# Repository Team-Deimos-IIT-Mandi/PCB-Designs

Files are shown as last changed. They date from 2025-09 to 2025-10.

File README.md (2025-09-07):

# PCB-Designs Repository

**Team Deimos - IIT Mandi**





This repository contains PCB designs for various robotic systems including drive systems, power distribution, robotic arm control, and miscellaneous components developed by Team Deimos.

## 🖼️ Featured Designs

<table>
<tr>
<td width="50%">

### Power Distribution Network
Power Distribution PCB
*24V to 5V Buck Converter with Protection*

</td>
<td width="50%">

### Motor Control PCB
Motor Control PCB
*Rover Motor Control with ESP32 & CAN*

### Integrated Drive PCB
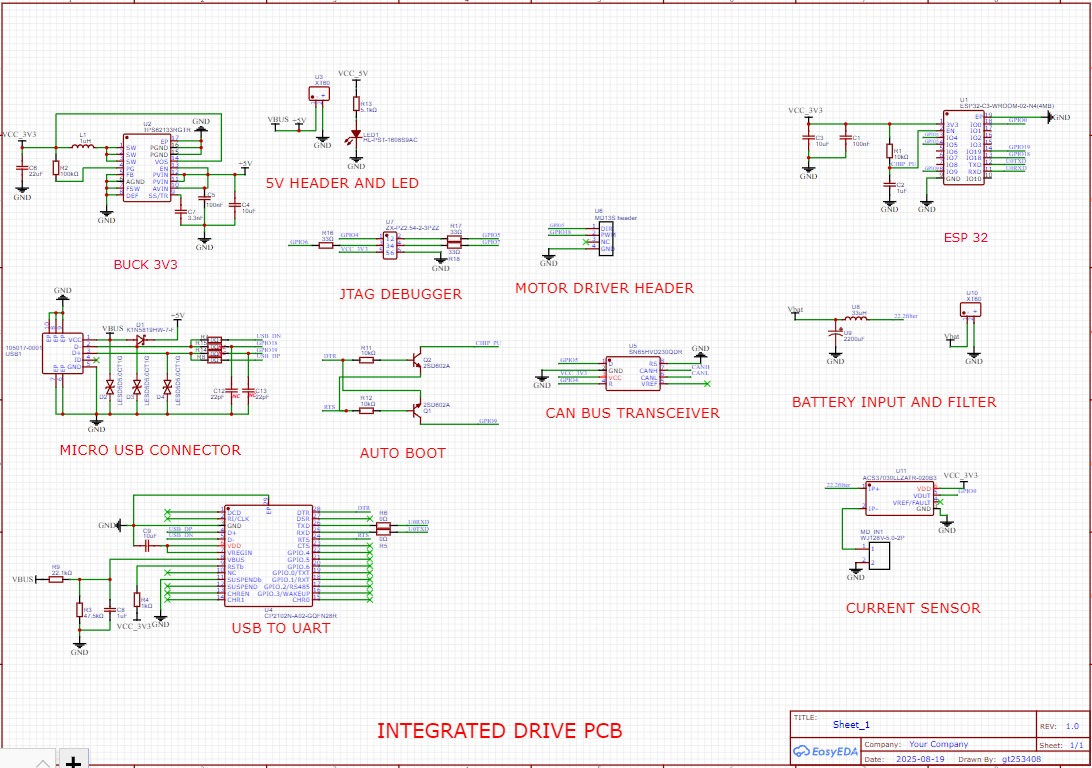
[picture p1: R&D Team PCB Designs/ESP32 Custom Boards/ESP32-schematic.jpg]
Integrated Drive PCB schematic

*Integrated PCB for drive with CAN*

</td>
</tr>
</table>

## 🚀 Overview

Our PCB designs are organized into specialized teams focusing on different aspects of robotic system development:

- **R&D Team**: Research and development of innovative PCB solutions
- **Testing Team**: Validation and testing of PCB designs in real-world scenarios

## 📁 Repository Structure

```
PCB-Designs/
├── R&D Team PCB Designs/          # R&D team developments
│   ├── Power Distribution/        # PDN and power management
│   ├── ESP32 Custom Boards/       # Custom ESP32 developments
│   └── Documentation/             # Design docs and specifications
├── Testing Team PCB Designs/      # Testing and validation
│   ├── Motor Control/             # Motor driver PCBs
│   ├── BOM Files/                 # Bill of Materials
│   └── Test Results/              # Testing documentation
└── Documentation/                 # Shared documentation
```

## 🔧 Current Projects

### R&D Team Projects

PDN Schematic

- **Power Distribution Network (PDN)**: 24V to 5V buck converter with surge protection
- **Custom ESP32 Board**: Development board with CAN headers and motor driver integration

### Testing Team Projects

Motor Control 3D

- **Rover Motor Control**: PCB for rover motor control systems
- **Component Testing**: Validation of motor drivers and sensors

## 📊 Quick Stats





- **Active Teams**: 2 (R&D & Testing)
- **Current PCB Designs**: 4+
- **Latest Update**: August 2025

### 🚀 Project Status Overview

```mermaid
gantt
    title PCB Development Timeline
    dateFormat  YYYY-MM-DD
    section R&D Team
    Power Distribution    :done,    pdn, 2025-07-01, 2025-08-20
    ESP32 Custom Board   :active,  esp32, 2025-08-01, 2025-10-15
    section Testing Team
    Motor Control PCB    :done,    motor, 2025-07-15, 2025-08-20
    Field Testing        :active,  test, 2025-08-20, 2025-09-30
```

## 🛠️ Design Tools

- **PCB Design**: KiCad, Altium Designer
- **3D Modeling**: Integrated PCB 3D viewers
- **Documentation**: Markdown, PDF exports

## 📋 Getting Started

1. Navigate to the appropriate team folder
2. Review the team-specific README files
3. Check the latest design files and documentation
4. Follow the design guidelines in each team's folder

## 🤝 Contributing

1. Fork the repository
2. Create a feature branch for your PCB design
3. Document your design thoroughly
4. Submit a pull request with detailed description

## 📞 Contact

For questions about specific designs, please refer to the team-specific README files or contact the respective team leads.

---

<div align="center">

### 🏆 Team Deimos - IIT Mandi




**Building the Future of Robotics, One PCB at a Time**





*Last Updated: September 2025*

</div>

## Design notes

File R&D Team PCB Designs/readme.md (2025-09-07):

# R&D Team PCB Designs




## 🔬 Mission Statement
Research and develop fully custom, efficient, and compact PCB solutions for advanced robotic systems.

## 🖼️ Design Gallery

<div align="center">

### Power Distribution Network - 3D View
PDN 3D View

### Schematic Overview
PDN Schematic

### Integrated Drive PCB
Integrated Drive PCB schematic
*Integrated PCB for drive with CAN*

</div>

## 🚀 Current Projects

### 1. Power Distribution Network (PDN)
**Status**: ✅ Completed Design Phase

Custom Power Distribution PCB designed for robust power management in robotic systems.

#### Features:
- **Input**: 24V DC input with XT90 connector
- **Output**: 5V regulated output via buck converter
- **Protection**: 
  - Reverse polarity protection
  - Surge protection circuitry
  - 60A fuse protection
- **Additional**: EMI filters for clean power delivery

#### Files:
- `PCB_PCB1_2025-08-20.pdf` - PCB layout documentation
- `3D_PCB1_2025-08-20.png` - 3D visualization
- `SCH_Schematic1_1-P1_2025-08-20.png` - Schematic diagram

### 2. Custom ESP32 Development Board
**Status**: 🔄 In Development

Creating a specialized ESP32 development board optimized for robotic applications with minimal external wiring.

#### Features:
- **Core**: ESP32-WROOM-32 module
- **Connectivity**: 
  - Onboard CAN bus headers (SN65HVD230)
  - Motor driver connection headers
- **Sensors**: Integrated current sensing capability
- **Design Goal**: Reduce wiring complexity in robotic systems

#### Target Applications:
- Rover control systems
- Motor control nodes
- Sensor data acquisition
- Wireless communication hubs

## 📋 Design Guidelines

### PCB Design Standards:
- **Layer Count**: Minimum 4-layer for complex designs
- **Trace Width**: Follow IPC standards
- **Via Size**: 0.2mm minimum drill, 0.4mm pad
- **Component Selection**: Prefer automotive/industrial grade components

### Documentation Requirements:
- Complete schematic with proper annotations
- 3D PCB visualization
- Assembly drawings
- BOM with supplier information
- Design review checklist

## 🛠️ Tools & Software

- **Primary**: KiCad 7.x
- **Secondary**: Altium Designer (for complex designs)
- **3D Modeling**: KiCad 3D Viewer, FreeCAD
- **Simulation**: LTSpice, KiCad Spice

## 📈 Future Roadmap

### Q4 2025 Goals:
- [ ] Complete ESP32 custom board prototyping
- [ ] PDN testing and validation
- [ ] Motor driver integration board
- [ ] Sensor fusion PCB development

### 2026 Vision:
- Develop modular PCB ecosystem
- Implement advanced power management
- Create standardized connector systems
- Establish automated testing protocols

## 🔍 Testing Protocols

All designs undergo rigorous testing phases:
1. **Design Rule Check (DRC)**
2. **Electrical Rule Check (ERC)**
3. **Thermal simulation**
4. **EMI/EMC pre-compliance testing**
5. **Prototype validation**

## 📞 R&D Team Contact

For technical discussions, design reviews, or collaboration opportunities, please reach out to the R&D team leads.

---

*R&D Team - Team Deimos IIT Mandi*  
*Last Updated: September 2025*

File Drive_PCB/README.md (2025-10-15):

<!-- @format -->

# Technical Design Document & Reviewer's Guide

**Project**: High-Performance ESP32-S3 Motor Controller  
**Version**: 1.0  
**Date**: September 15, 2025  
**Designer**: Team Deimos

---

## 1. Overview

This document provides a detailed technical overview of the custom PCB designed for the control and monitoring of a brushed DC motor. The board is intended for robotics and automation applications where performance, real-time feedback, and network integration are critical.

The design philosophy emphasizes robustness, efficiency, and modularity. This README serves as a guide for technical review, detailing the function of each subsystem and the engineering rationale behind key component selections and circuit designs.

---

## 2. System Architecture

The board is architected around a central ESP32-S3 microcontroller. A two-stage power delivery network provides clean, stable power to all components. The system integrates high-current motor driving, precision current sensing, high-resolution encoder feedback, and CAN bus communication.

System Architecture Diagram

### 3D PCB Render

A 3D render of the custom PCB, showing key connectors and component placements:

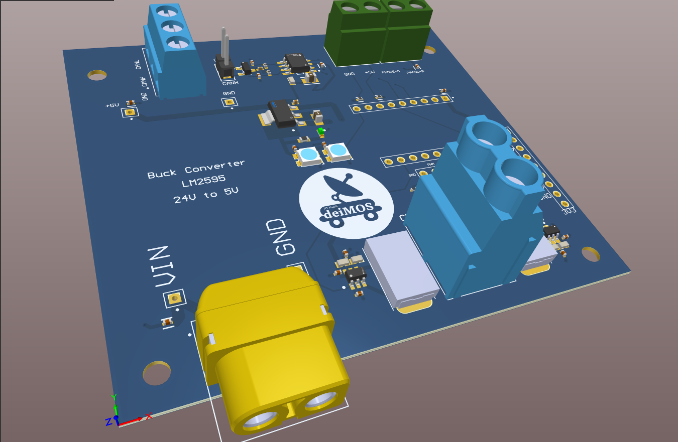
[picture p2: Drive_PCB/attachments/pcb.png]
3D PCB Render


---

## 3. Subsystem Deep Dive & Design Rationale

This section details the function and component choices for each block of the schematic.

### 3.1. Power Delivery Network (PDN)

A two-stage hybrid power regulation strategy was chosen for optimal efficiency and noise performance.

#### Stage 1: Buck Converter (12V → 5V)

- **Function:** Handles the large initial voltage drop from the main 12V input. This stage powers the 5V rail required by the motor encoder.
- **Component Rationale:** A buck converter (e.g., based on the LM2596) is used here for its high efficiency (>85%). Using an LDO for this large voltage step would be thermally unmanageable and waste significant power.

#### Stage 2: LDO (5V → 3.3V)

- **Function:** Provides a final, clean, and stable 3.3V rail for all sensitive logic components, including the ESP32, CAN transceiver, and current sense amplifiers.
- **Component Rationale (AZ1117CH-3.3TRG1):**
  - **Low Noise:** The LDO acts as a filter, removing the switching noise (ripple) from the preceding buck stage, which is critical for the accuracy of the ADC readings.
  - **High Current & Thermal Headroom:** The AZ1117CH is rated for 1A and comes in a SOT-223 package. This provides a substantial safety margin over the ESP32's peak current draw (~500mA) and its package is designed to effectively dissipate the heat generated (~0.8W) into a PCB copper pour.

### 3.2. Microcontroller (MCU)

- **Component:** Waveshare ESP32-S3-Zero
- **Rationale:** This module was selected for its powerful dual-core processor and rich set of integrated peripherals, which are leveraged as follows:
  - **LEDC Peripheral:** Used for generating the stable, hardware-based PWM signal for motor speed control.
  - **PCNT (Pulse Counter) Peripheral:** Used for hardware quadrature decoding of the encoder signals. This offloads the CPU entirely from the high-frequency task of counting pulses.
  - **ADC Peripheral:** Used to read the analog voltage output from the current sense amplifiers.
  - **TWAI (CAN) Controller:** The native CAN controller is used for reliable network communication.

### 3.3. Encoder Interface

- **Function:** To safely read the signals from a 5V-powered NPN open-collector encoder with the 3.3V logic of the ESP32.
- **Design Rationale:** A dedicated level-shifter IC was intentionally avoided. Instead, a simple pull-up resistor network is used. Each signal line from the encoder is connected to an ESP32 GPIO pin and simultaneously pulled up to the 3.3V rail with a 4.7kΩ resistor.
  - **How it Works:** When the encoder's open-collector output is inactive (high-impedance), the resistor pulls the GPIO pin up to a safe 3.3V. When the encoder output activates, it pulls the line down to 0V. This is a robust, low-cost, and component-efficient method for level shifting this specific type of signal.

### 3.4. Current Sensing

- **Function:** To provide real-time measurement of the current flowing to the motor. A low-side sensing topology is used.
- **Component Rationale:**
  - **Shunt Resistor (WSR32L000FEA):** A very low resistance (2mΩ) shunt is chosen to minimize power loss (I²R) in the high-current motor path.
  - **Amplifier (INA181A3IDBVR):** The INA181 is a precision current sense amplifier. The 'A3' version has a fixed gain of 100 V/V. This specific gain was chosen to map the expected motor current range to the ESP32's ADC input range.
    - **Calculation:** At a max current of 13A, the voltage across the shunt is 13A _ 0.002Ω = 26mV. Amplified by the gain of 100, the output is 26mV _ 100 = 2.6V, which fits perfectly within the ESP32's 0-3.3V ADC range.

### 3.5. Directional LED Indicators

- **Function:** Provide visual feedback of the motor's direction using a single GPIO pin.
- **Design Rationale:** This circuit uses a complementary pair of transistors (one NPN, one PNP) to drive two separate LEDs from one control signal.
  - **NPN Transistor (SS8050-G):** Wired as a standard low-side switch. It turns ON and lights its corresponding LED when the GPIO pin is HIGH.
  - **PNP Transistor (SMMBT3906WT1G):** Wired as a standard high-side switch. It turns ON and lights its corresponding LED when the GPIO pin is LOW.
  - **Benefit:** This design is highly efficient, requires no special logic ICs, and conserves precious GPIO pins.

### 3.6. Programmable Status LED

- **Component:** SK6812MINI-HS Addressable RGB LED.
- **Rationale:** This specific "smart" LED was chosen because it is 3.3V-native. It can be powered by and controlled directly from the 3.3V rail and a standard ESP32 GPIO pin without requiring the level-shifting circuitry that 5V addressable LEDs need. This simplifies the design and increases reliability. Two are chained together for expanded status indication.

---

## 4. Areas for Review

Particular attention is requested on the following aspects of the design:

- **PCB Layout:** Review of the high-current paths for the motor driver and the placement of decoupling capacitors for the power regulators and sensitive ICs.
- **Thermal Management:** Confirmation that the copper pour for the SOT-223 LDO is sufficient for heat dissipation.
- **Signal Integrity:** Review of the encoder and CAN bus trace routing to ensure they are adequately shielded from the noisy motor driver section.

---

_End of Document_

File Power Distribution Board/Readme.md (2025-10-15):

## Power Distribution Board
A compact, 4-layer Power Distribution Board (PDB) designed for robust and reliable power management. This board takes a single DC input(max voltage 36V, max current 100A) and provides multiple fused outputs at 24V and 5V, with comprehensive protection features suit.

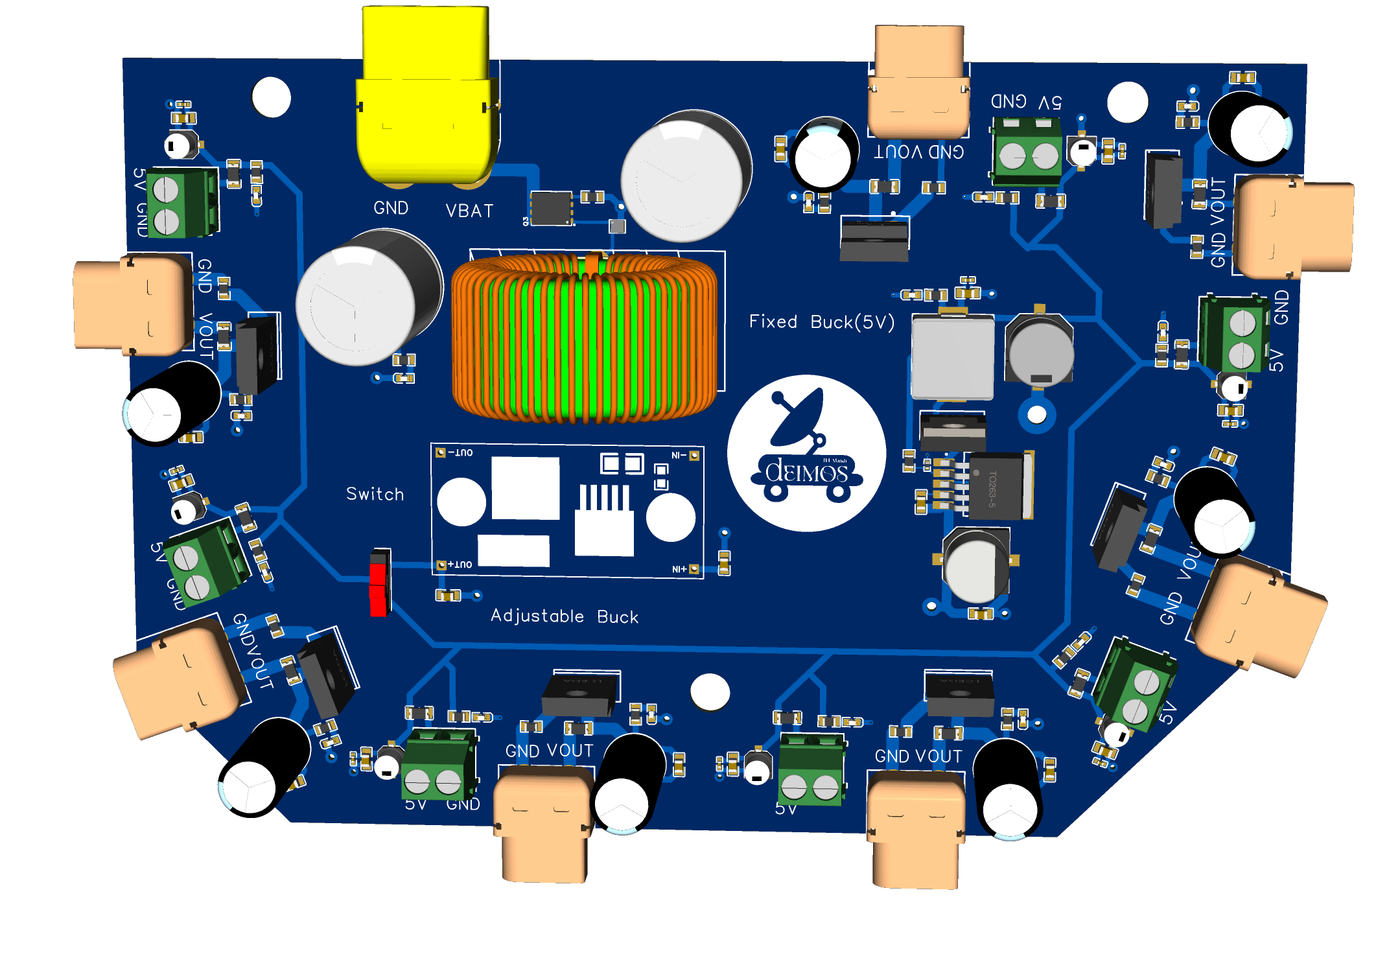
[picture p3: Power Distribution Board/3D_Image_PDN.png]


## Features ⚡️
Dual Voltage Rails: Provides both high-power 24V and low-power 5V outputs.

Robust Input Protection:

ESD (Electrostatic Discharge) protection.

LC filter for noise reduction.

MOSFET-based reverse polarity protection.

Large bulk capacitance for input stability.

Individually Fused Outputs: Each output channel is protected by its own fuse, preventing a single fault from taking down the entire system.

High-Efficiency 5V Rail: Utilizes a high-efficiency XL4015E1 buck converter capable of delivering up to 5A.

Selectable Variable Voltage: Two 5V ports are connected to an LM2596 module, providing a switch-selectable variable voltage output for special components.

4-Layer PCB Design: Features dedicated power and ground planes for excellent electrical performance, low noise, and improved thermal management.

All important components and connectors labeled in silkscreen

## Specifications
Specification	Value	Notes
Input Voltage	~26V - 40V DC	Input must be higher than 24V
24V Outputs	7	Each fused at 30A. Pass-through from input voltage.
5V Fixed Outputs	5	Each fused at 1A.
5V Variable Outputs	2	Controlled by an LM2596 module and a selector switch.
Max Total 5V Current	5A	Limited by the XL4015E1 buck converter.
PCB Layers	4	Signal, GND, Vin (24V), 5V
Primary 5V Converter	XL4015E1	High-efficiency synchronous buck converter.
Variable Voltage Converter	LM2596 Module	Adjustable step-down voltage regulator.

## Board Layout and Connections 🔌
Layer Stack-up
The 4-layer design is critical for the board's performance:

Top Layer: Signal traces and component placement.

Layer 2: Solid Ground Plane (GND).

Layer 3: Input Voltage Plane (Vin / 24V).

Bottom Layer: 5V Power Plane.

Connectors
1. 7 Xt60 connectors for 24V outputs
2. Xt90 for battery input
3. 7 screw terminals for 5V outputs

## How to Use
Verify Fuses: Ensure the correct fuse ratings (30A for 24V, 1A for 5V) are installed in all slots you intend to use.

Connect Input Power: Connect your main DC power supply to the J1 input terminal. The reverse polarity protection will prevent damage from incorrect wiring, but it's always best to double-check.

Connect Devices:

Connect your 24V devices to the XT60 connectors. Do not exceed 30A on any single port.

Connect your standard 5V devices (e.g., microcontrollers, sensors) to the OUT_5V headers. Remember the total current for all 5V devices should not exceed 5A.

Using Variable Outputs:

To use the variable outputs, flip switch to the ON position.

Before connecting a device, use a multimeter to measure the voltage on output of the moudle

Carefully turn the potentiometer to set your desired voltage (e.g., 3.3V, 1.8V).

Once the voltage is set, you can connect your device.

## Note
If you want a higher current in 5V outputs, carefully replace xl4015 with xl4016 which provides 7A current and has the same shape and footprint

The prices listed in the BOM are approximate.

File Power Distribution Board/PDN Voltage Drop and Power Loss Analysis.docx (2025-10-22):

PDN Voltage Drop and Power Loss Analysis (Absolute Maximum Values)

Voltage Drop

- 24 V Rail
  - Main MOSFET: 0.30 V
  - Secondary MOSFETs (combined): 0.78 V
  - Inductor: 0.01 V
  - Other components – Negligible
  - Copper pours – 0.13V
  - 24V traces – 0.2V
  - Total Voltage Drop (24 V rail): 1.42 V
- 5 V Rail
  - All components – Negligible
  - 5V traces – 0.1 V
  - Total Voltage Drop (5 V rail): 0.1 V

Power Loss

- Main MOSFET: 30 W
- Secondary MOSFETs (7 devices, each up to 23.4W): 163 W (absolute max)
- ESD Diode: 24 µW (negligible)
- Main Bulk Capacitor: 0.74 W
- LC Filter: 0.74 W
- Main Buck Converter: 3.73 W
- Secondary Buck Converter: 6.75 W (only one active at a time; take maximum = 6.75 W)
- Switch: 0.35 W
- 5V traces 0.13W
- 24V traces 1.2W
- Copper pours 1.4W
- Other components: 0.10 W (lumped estimate)

Total Power Loss (worst-case, absolute maximum):
= 30 W (Main MOS) + 163 W (Secondary MOS, worst one) + 0.74 W (Bulk) + 0.74 W (LC filter) + 3.73 W (Main Buck) + 6.75 W (Secondary Buck) + 0.35 W (Switch) + 2.73W(copper)+ 0.10 W (Others)
= 209.04 W (43% of battery per hour)

Notes

- Considering changing the secondary mosfet to reduce the power and voltage drop.

Maybe we will switch to nmos with high side gate driver(much more complex but very low power loss)

Normal case scenario

- Taking 40% of stall current as normal working current and only 4 motors at outputs, net current becomes 40A. Voltage drop = 0.45V(approx.)
- Take main buck
- Power loss = 32W (6.7% of battery per hour)

Constants

- Copper resistivity (ρ) at ~20°C: 1.724×10⁻⁸ Ω·m
- Copper temperature coefficient (α) ≈ 0.00393 /°C (for temperature correction).
- 1 oz copper thickness: t = 35 µm = 35×10⁻⁶ m.
- Sheet resistance for 1 oz copper: R_(sheet) =ρ/t=(1.724×10^(-8))/(35×10^(-6))=4.925714×10^(-4) Ω/square .

Fundamental formulas

Trace resistance:
R=(ρ⋅L)/(w⋅t) where L = trace length (m), w = width (m), t = copper thickness (m).

- Voltage drop (DC): V_(drop) =I⋅R
- Copper power loss: P=I^2 ⋅R=I⋅V_(drop)
- Sheet/plane resistance (squares): Number of squares N_(sq) =(path length)/(effective width) (both in same units) R_(plane) =R_(sheet) ⋅N_(sq)
- Plane loop approximation (VIN→GND): R_(loop) ≈R_(plane,VIN) +R_(plane,GND) (often ≈ 2 × R_plane if both planes identical and path similar)
- Temperature correction: R(T)=R_(20^(∘) C) ⋅[1+α⋅(T-20^(∘) C)]
- Approximate via barrel resistance (solid cylinder approx): R_(via) ≈(ρ⋅L_(via))/(A_(via)) , where A_(via) =π((D_o^2 -D_h^2)/4) (outer barrel OD and plated hole ID). Use actual via geometry for accuracy.

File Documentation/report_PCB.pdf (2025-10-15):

## Technical Report: High-Performance ESP32-S3 Motor Controller

Team Deimos
September 15, 2025

## Executive Summary

This report presents the technical design and engineering rationale for a custom PCB developed to control and monitor a brushed DC motor for robotics and automation applications. The design focuses on robustness, efficiency, modularity, and real-time feedback, with strong integration for networked environments.

## 1 System Overview

The motor controller PCB is designed around the ESP32-S3 microcontroller, integrating high-current motor driving, precision current sensing, encoder feedback, and CAN bus communication. The power delivery system uses a two-stage approach for stable, low-noise operation.

## 2 System Architecture

- Central MCU: ESP32-S3, managing control, sensing, and communication.
- Power Delivery: Two-stage network (Buck converter and LDO) for regulated supply.
- Motor Driver: High-current output with current sensing and direction indication.
- Encoder Interface: Robust signal level adaptation for high-resolution feedback.

1

- CAN Communication: Reliable, hardware-backed network interface.

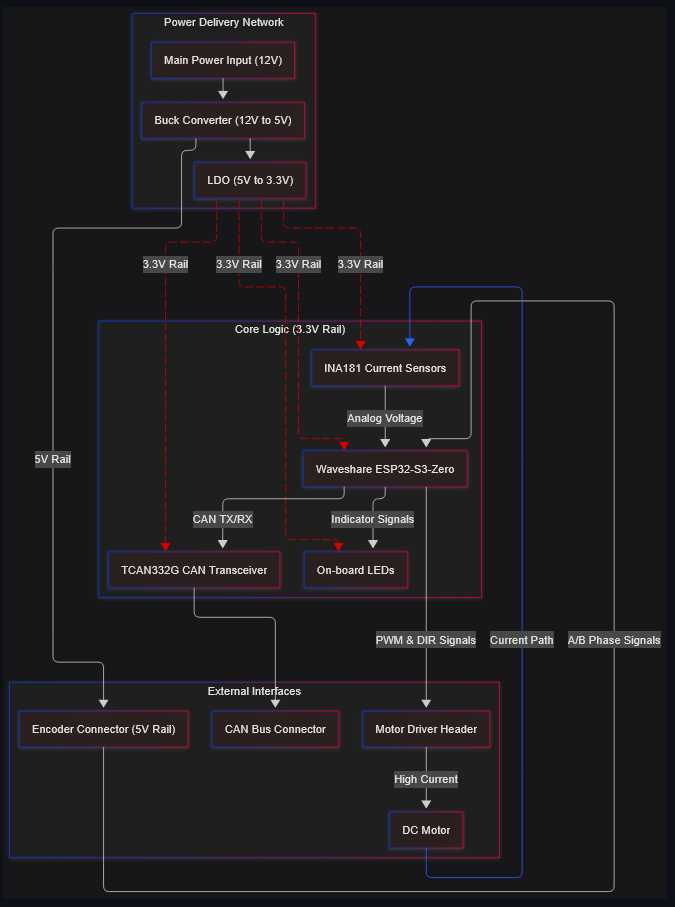
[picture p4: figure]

Figure 1: System Architecture Diagram

2

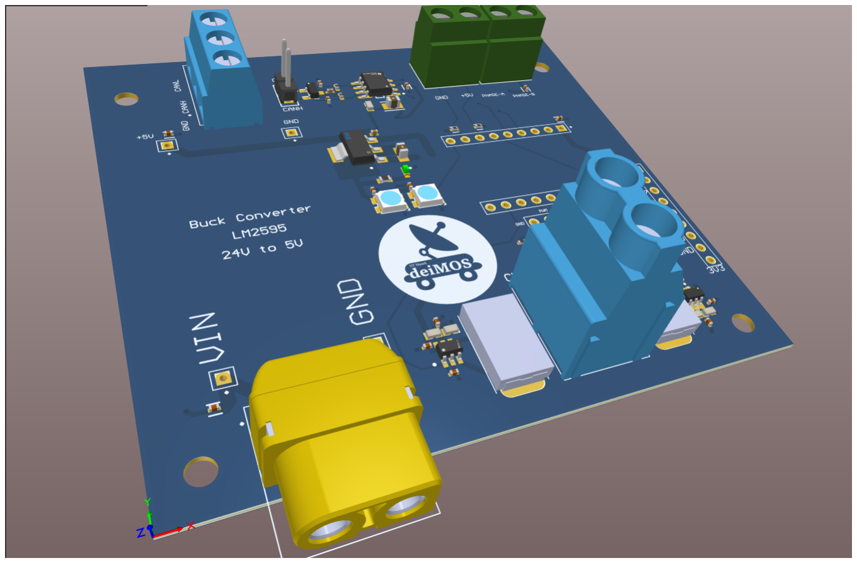
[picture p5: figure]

Figure 2: 3D PCB Render

## 3 Subsystem Deep Dive & Design Rationale

### 3.1 Power Delivery Network (PDN)

Stage 1: Buck Converter (12V → 5V)
Handles initial voltage drop, powering the 5V rail for the encoder. A buck converter, e.g., LM2596, is selected for high efficiency (>85%). LDOs are unsuitable due to poor thermal performance at this step.
Stage 2: LDO (5V → 3.3V)
Provides a low-noise, stable 3.3V rail for logic, sensing, and communication. The AZ1117CH-3.3TRG1 LDO offers:
- Low output noise (critical for ADC accuracy)
- Ample current capacity (1A rating vs. ∼500mA MCU peak)
- Good thermal properties (SOT-223 package with copper pour)

### 3.2 Microcontroller (MCU)

Component: Waveshare ESP32-S3-Zero
Chosen for its dual-core processing and rich peripherals:

3

- LEDC: Hardware PWM for motor speed control.
- PCNT: Hardware quadrature decoding for encoder signals.
- ADC: Analog input for current sense amplifier.
- TWAI: Native CAN controller for network integration.

### 3.3 CAN Communication System

The adoption of CAN bus communication over previously used I2C provides several critical advantages for our motor controller design:
- Superior Noise Immunity: CAN’s differential signaling provides excellent resistance against electromagnetic interference, addressing the significant noise issues we previously encountered with I2C in high-current motor environments.
- Robust Error Detection: CAN’s built-in CRC and acknowledgment mechanisms ensure data integrity in electrically noisy environments.
- Reliable Long-Distance Communication: Unlike I2C’s limited range, CAN allows communication distances up to 1km, facilitating reliable ESP32-Jetson integration across our robot’s chassis.
- Multi-Master Capability: CAN’s inherent support for multiple nodes without master-slave limitations provides flexibility in system architecture and expansion.
- Real-Time Performance: CAN’s deterministic collision resolution ensures timely delivery of critical motor control commands, a limitation previously observed with I2C.
The transition to CAN has eliminated the communication failures previously experienced with I2C, particularly during high-torque motor operations when communication reliability is most crucial.

### 3.4 Encoder Interface

Facilitates safe reading of 5V NPN open-collector encoder signals using the ESP32’s 3.3V logic. A resistor pull-up network (4.7kΩ) adapts the signal, eliminating the need for level-shifter ICs.

4

### 3.5 Current Sensing

Provides real-time motor current measurement using low-side topology:
- Shunt Resistor (WSR32L000FEA): 2mΩ for minimal power loss.
- Amplifier (INA181A3IDBVR): Precision sense, fixed gain (100 V/V), mapping 13A max current to ∼2.6V ADC input.

### 3.6 Directional LED Indicators

Visual feedback for motor direction is provided by a complementary transistor pair (NPN: SS8050-G, PNP: SMMBT3906WT1G), enabling two LEDs to be driven by a single GPIO pin.

### 3.7 Programmable Status LED

Uses SK6812MINI-HS addressable RGB LEDs (3.3V native), allowing direct MCU control without level shifting. Two LEDs are chained for expanded status indication.

## Conclusion

This motor controller PCB exemplifies high-performance, modular design for robotic applications, integrating robust power delivery, precise feedback, and reliable communication. Your technical review and feedback are welcomed for further refinement.

5

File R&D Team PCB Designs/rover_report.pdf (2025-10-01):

## Integrated Power Analysis and Battery Justification for Rover System

(Full Drivetrain Calculations + Gripper Analysis)

Prepared for: Team Deimos IIT Mandi Prepared by: Gaurav Tiwari, Aayan Garg and Banoth Tharun

September 29, 2025

Abstract

This report merges the drivetrain and battery guidance from the uploaded system report with a detailed Gripper Power Analysis (2×28BYJ-48 steppers + 2×SG90 servos). All key arithmetic is shown explicitly. The document gives per-component power, battery-side draws at the nominal 24 V bus, runtime tables for 24 V 20 Ah and 35 Ah packs across typical driving scenarios, peak current considerations, and procurement recommendations.

## Contents

1 Overview | 1
2 Base numbers and assumptions | 2
3 Drivetrain detailed calculations | 2
4 Gripper analysis (integrated) | 4
5 Sizing & procurement recommendations (full) | 5
6 Summary | 6

## 1 Overview

This document contains:

1. Full drivetrain power calculations (digit-by-digit) derived from the original uploaded report.

2. Ancillary electronics and gripper power analyses.
3. Integrated runtime tables for several realistic scenarios: straight driving, turning, climbing, and heavy loads.
4. Peak/stall current treatment and wiring/protection recommendations.
5. A one-page purchase justification summary.

## 2 Base numbers and assumptions

- System nominal bus voltage: 24 V (from original report).
- Battery candidates: 24 V, 20 Ah (480 Wh) and 24 V, 35 Ah (840 Wh).
- Drivetrain continuous baseline (from uploaded report): 384 W combined for 4 wheel motors (used as a baseline).
- Reported typical current ranges (from uploaded report): straight driving ≈ 12 A to 15 A, turning ≈ 15 A to 18 A, climbing ≈ 20 A to 25 A, reported continuous ≈ 16.7 A, stall bursts up to ≈ 120 A.
- DC–DC (24→5 V) converter efficiency assumed: η = 0.90.
- Two electronics budgets used for scenario comparison:

– Light electronics (MCU, sensors, telemetry): 30W (actuator-side) → battery-side 30/0.9 = 33.333 . . . W.

– Heavy electronics (Raspberry Pi, camera, heavier payload): 75W → battery-side 75/0.9 = 83.333 . . . W.

- Gripper battery-side draw (from gripper analysis): Pgripper,bat =

6.8 W
0.9

= 7.5555555556 W
(see Section 4).

## 3 Drivetrain detailed calculations

We compute motor power for several currents (digit-by-digit) and add electronics + gripper draws.

### 3.1 Motor power at 24 V

Power P = V × I. Using V = 24 V.

At I = 12 A : P = 24 × 12 = 288 W.
At I = 15 A : P = 24 × 15 = 360 W.
At I = 16.7 A : P = 24 × 16.7 = 24 × 16.7 = 400.8 W. At I = 18 A : P = 24 × 18 = 432 W.
At I = 20 A : P = 24 × 20 = 480 W.
At I = 25 A : P = 24 × 25 = 600 W. At I = 120 A (stall) : P = 24 × 120 = 2880 W.

Notes:

- The original report quoted a combined continuous motor electrical power ≈ 384W which equates to about 16 A at 24 V; report also quoted ≈ 16.7 A as a typical figure (400.8 W). Both are consistent baselines.
- Stall power is extremely large (2880 W) and only occurs in brief bursts — design wiring and motor drivers to safely handle stall currents; do not expect to sustain stall power for runtime calculations.

### 3.2 Add electronics + gripper contributions

We add the battery-side electronics and gripper contributions to form total battery-side draw for each scenario.

Let:

Pelec,light =

30
0.9

= 33.333333333333336 W,

Pelec,heavy =

75
0.9

= 83.33333333333334 W,

Pgripper,bat =

6.8
0.9

= 7.555555555555555 W.

Therefore for a given motor power Pmotor:

Ptotal,light = Pmotor + Pelec,light + Pgripper,bat,

Ptotal,heavy = Pmotor + Pelec,heavy + Pgripper,bat.

### 3.3 Runtimes (digit-by-digit) for 20 Ah and 35 Ah

Battery energies:

E20 = 24 × 20 = 480 Wh, E35 = 24 × 35 = 840 Wh.

Compute total draws and runtimes (hours) for representative currents. The arithmetic below is explicit.

Scenario | Motor power (W) | Total (light) (W) | Runtime on 20Ah (h) | Runtime on 35Ah (h)
Straight (12 A) | 24 × 12 = 288 | 288 + 33.3333 + 7.5556 = 328.8889 | 480/328.8889 = 1.45946 h | 840/328.8889 = 2.55405 h
Straight (15 A) | 24 × 15 = 360 | 360 + 33.3333 + 7.5556 = 400.8889 | 480/400.8889 = 1.19734 h | 840/400.8889 = 2.09534 h
Reported continuous (16.7 A) | 24 × 16.7 = 400.8 | 400.8 + 33.3333 + 7.5556 = 441.6889 | 480/441.6889 = 1.08674 h | 840/441.6889 = 1.90179 h
Turning (18 A) | 24 × 18 = 432 | 432 + 33.3333 + 7.5556 = 472.8889 | 480/472.8889 = 1.01532 h | 840/472.8889 = 1.77735 h
Climbing (20 A) | 24 × 20 = 480 | 480 + 33.3333 + 7.5556 = 520.8889 | 480/520.8889 = 0.92166 h | 840/520.8889 = 1.61302 h
Climbing heavy (25 A) | 24 × 25 = 600 | 600 + 33.3333 + 7.5556 = 640.8889 | 480/640.8889 = 0.74896 h | 840/640.8889 = 1.31068 h

The same table but for heavy electronics (Pelec,heavy = 83.3333 W) — useful when using
Raspberry Pi + camera:
Scenario | Motor power (W) | Total (heavy) (W) | Runtime on 20Ah (h) | Runtime on 35Ah (h)
Straight (12 A) | 288 | 288 + 83.3333 + 7.5556 = 378.8889 | 480/378.8889 = 1.26686 h | 840/378.8889 = 2.21701 h
Straight (15 A) | 360 | 360 + 83.3333 + 7.5556 = 450.8889 | 480/450.8889 = 1.06456 h | 840/450.8889 = 1.86299 h
Reported continuous (16.7 A) | 400.8 | 400.8 + 83.3333 + 7.5556 = 491.6889 | 480/491.6889 = 0.97623 h | 840/491.6889 = 1.70840 h
Turning (18 A) | 432 | 432 + 83.3333 + 7.5556 = 522.8889 | 480/522.8889 = 0.91828 h | 840/522.8889 = 1.60685 h

Scenario | Motor power (W) | Total (heavy) (W) | Runtime on 20Ah (h) | Runtime on 35Ah (h)
Climbing (20 A) | 480 | 480 + 83.3333 + 7.5556 = 570.8889 | 480/570.8889 = 0.84099 h | 840/570.8889 = 1.47109 h
Climbing heavy (25 A) | 600 | 600 + 83.3333 + 7.5556 = 690.8889 | 480/690.8889 = 0.69476 h | 840/690.8889 = 1.21583 h

### 3.4 Notes on the tables

- All arithmetic is explicit: motor power computed as 24 × I (W), electronics are scaled by the converter efficiency, and totals are summed before dividing into battery Wh to compute runtime.
- Differences between light and heavy electronics examples show how payloads like a camera/RPi reduce runtime substantially.
- Stall events (e.g., 120 A) are not usable for runtime—they are short bursts that stress wiring and the BMS. Example: stall power = 24 × 120 = 2880 W (instantaneous).

## 4 Gripper analysis (integrated)

This is the gripper analysis previously computed and now referenced within the integrated runtimes.

### 4.1 Components and typical currents

- 2 × 28BYJ-48 stepper motors: 5 V, typical active current ≈ 0.48 A per motor.
- 2 × SG90 micro servos: 5 V, moving current ≈ 0.20 A per servo, stall ≈ 1.3 A.

### 4.2 Actuator-side power (explicit)

Pstepper,per = 5.0 × 0.48 = 2.4 W.

Pservo,per = 5.0 × 0.20 = 1.0 W.

Total actuator-side moving power:

Pact = 2 × 2.4 + 2 × 1.0 = 6.8 W.

Battery-side (24 V bus) with η = 0.9:

Pbat =

6.8
0.9

= 7.5555555556 W.

Battery-side current at 24 V:

Ibat =

7.5555555556
24

= 0.3148148148 A ≈ 0.315 A.

### 4.3 Energy per grip (2 s)

t =

2
3600

= 0.0005555555556 h.

Eop = 7.5555555556 × 0.0005555555556 = 0.0041975308642 Wh.

This energy is negligible relative to battery capacity (see runtime tables).

### 4.4 Peak/stall sizing for the gripper

Worst-case actuator-side peak (both servos stalled, steppers active):

Pact,peak = 2 × (5.0 × 0.48) + 2 × (5.0 × 1.3) = 4.8 + 13.0 = 17.8 W,

Pbat,peak =

17.8
0.9

= 19.7777777778 W,

Ibat,peak =

19.7777777778
24

= 0.8240740741 A ≈ 0.82 A.

## 5 Sizing & procurement recommendations (full)

### 5.1 Battery selection

- For 1–2 hour operation under typical cruising loads, a 24 V, 35 Ah pack (840Wh) is recommended.
- For ≈4 hours at cruising load, required energy is:

Ereq = Pcruise × 4 ≈ 417.33 × 4 = 1669.32 Wh,

Ahreq =

1669.32
24

≈ 69.56 Ah.

So choose ≈70–80 Ah @ 24 V (e.g., two matched 35 Ah packs in parallel, or one 70–80 Ah pack).

- Batteries must be rated to supply brief stall bursts (up to the reported 120 A). Choose pack with appropriate C-rating or parallel cells to support short high-current delivery.

### 5.2 DC–DC and 5 V rail

- 5 V buck converter: ≥ 3 A (15 W) recommended to handle servo stalls and steppers margin.
- 5 V rail fuse: 4 A slow-blow recommended.
- Local decoupling: 470–1000 µF low ESR electrolytic + 0.1 µF ceramic near servos.

### 5.3 Wiring, fuses and protection

- Main fuse: sized above expected continuous draw but below wiring limit; a practical main fuse of 100 A slow-blow is suggested given stall risk (tune after final motor-driver selection).
- Per-motor fuses (or current-limited motor drivers): 30 A or per-motor rating as recommended by motor driver datasheets.
- Use XT90 / Anderson connectors for high-current battery connections; AWG sized wiring for continuous and peak currents.
- BMS with balancing and cell monitoring; if paralleling packs, ensure safe paralleling procedure and compatible BMS.

## 6 Summary

System battery needs: Drivetrain continuous draw 384W ( 16 17A at 24 V). For 1–2 hours operation a 24 V, 35 Ah pack (840 Wh) is recommended. For ≈4 hours at cruising load choose 70 Ah (e.g., two 35 Ah packs in parallel). Battery must support short stall bursts up to reported 120 A.

Gripper: 2×28BYJ-48 steppers + 2×SG90 servos draw 6.8W actuator-side; battery-side 7.56W. One grip (2 s) uses 0.0042 Wh. Impact on main pack runtime is negligible; design local 5 V rail (≥ 3 A buck, 4 A fuse, decoupling caps) and wiring for servo stall currents.

Other procurement: 5 V buck (≥ 3 A), main fuse 100 A slow-blow (verify), per-motor fuses (per driver spec), XT90/Anderson connectors, AWG correct wiring, BMS with balancing, motor drivers rated for continuous and peak currents.

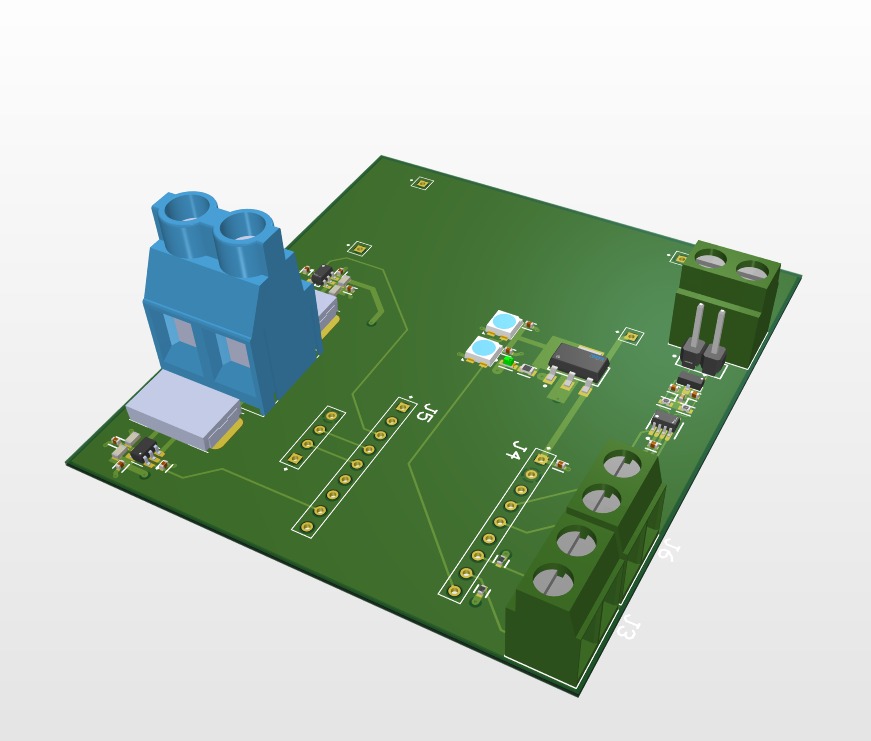
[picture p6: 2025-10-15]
Drive_PCB/attachments/3d_pcb.jpg

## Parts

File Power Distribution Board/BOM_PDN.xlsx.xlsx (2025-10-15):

Index | Manufacturer Part Number | Manufacturer Name | Description | Availability | Stock Status | Assemblies | Requested Quantity 1 | Pack Quantity 1 | Unit Price 1 | Total Price | Requested Part Number | Datasheet | US Import Tariff | Original Part numbers | Image
1 |  |  |  |  |  | 3 |  |  |  |  | Manufacturer Part |  |  | Manufacturer Part
2 | 50TZV220M10X10.5 | Rubycon | CAP ALUM 220UF 20% 50V SMD | 2,45,536 | In Stock | 3 | 2 | 6 | 76.13000 | ₹456.78 | 50TZV220M10X10.5 | https://www.rubycon.co.jp/wp-content/uploads/catalog-aluminum/TZV.pdf | N/A | 50TZV220M10X10.5 | https://mm.digikey.com/Volume0/opasdata/d220001/medias/images/505/6.3TZV1000M10X10.5.JPG
3 | CC0805KKX7R8BB105 | YAGEO | CAP CER 1UF 25V X7R 0805 | 74,277 | In Stock | 3 | 15 | 45 | 6.30000 | ₹283.50 | CC0805KKX7R8BB105 | https://www.yageogroup.com/content/datasheet/asset/file/UPY-GPHC_X7R_6_3V-TO-250V | N/A | CC0805KKX7R8BB105 | https://mm.digikey.com/Volume0/opasdata/d220001/medias/images/2485/0805%288%5E5mm%20thickness%29.jpg
4 | CC0402MRX7R7BB333 | YAGEO | CAP CER 0.033UF 16V X7R 0402 | 27,950 | In Stock | 3 | 10 | 30 | 2.62500 | ₹78.75 | CC0402MRX7R7BB333 | https://www.yageogroup.com/content/datasheet/asset/file/UPY-GPHC_X7R_6_3V-TO-250V | N/A | CC0402MRX7R7BB333 | https://mm.digikey.com/Volume0/opasdata/d220001/medias/images/2392/0402%280%5E50%20thickness%29.jpg
5 | 100ZLH100MEFC10X20 | Rubycon | CAP ALUM 100UF 20% 100V RADIAL | 30,844 | In Stock | 3 | 10 | 30 | 50.83800 | ₹1,525.14 | 100ZLH100MEFC10X20 | https://www.rubycon.co.jp/wp-content/uploads/catalog-aluminum/ZLH.pdf | N/A | 100V100uF CD288 | https://mm.digikey.com/Volume0/opasdata/d220001/medias/images/518/25ZLH1000MEFC10X20.JPG
6 | 865080442004 | Würth Elektronik | CAP ALUM 22UF 20% 25V SMD | 4,376 | In Stock | 3 | 6 | 18 | 17.50000 | ₹315.00 | 865080442004 | https://www.we-online.com/components/products/datasheet/865080442004.pdf | N/A | RST22UF16V024 | https://mm.digikey.com/Volume0/opasdata/d220001/medias/images/1046/MFG_WCAP-ASLI.jpg
7 | SL15T1G | onsemi | TVS DIODE 15VWM 30VC SOT233 | 1,864 | In Stock | 3 | 1 | 3 | 34.13000 | ₹102.39 | SL15T1G | https://www.onsemi.com/pdf/datasheet/sl05t1-d.pdf | N/A | ESD56161D24-3/TR | https://mm.digikey.com/Volume0/opasdata/d220001/medias/images/1168/SOT-23-3_527AG.jpg
8 | F1206HC30A0TM | AEM Components | SOLIDMATRIX FUSE, 35VDC, 30A | 0 | Normally Stocking | 3 | 6 | 18 | 65.18800 | ₹1,173.38 | F1206HC30A0TM | https://aemcomponents.media.zestyio.com/AEM-F1206HC.pdf | N/A | F1206HC30A0TM
9 | TR/3216FF30-R | Eaton - Electronics Division | FUSE BOARD MOUNT 30A 24VDC 1206 | 16,941 | In Stock | 3 | 6 | 18 | 111.03800 | ₹1,998.68 | TR/3216FF30-R | https://www.eaton.com/content/dam/eaton/products/electronic-components/resources/data-sheet/eaton-3216ff-surface-mount-fuse-data-sheet.pdf | N/A | BSMD1206C-1200T | https://mm.digikey.com/Volume0/opasdata/d220001/medias/images/2529/3216FF%20SERIES.jpg
10 | IHLP6767DZER470M11 | Vishay Dale | FIXED IND 47UH 5A 108.46MOHM SMD | 344 | In Stock | 3 | 1 | 3 | 259.00000 | ₹777.00 | IHLP6767DZER470M11 | https://www.vishay.com/docs/34306/ihlp-6767dz-11.pdf | N/A | YSPI1365-470M | https://mm.digikey.com/Volume0/opasdata/d220001/medias/images/2588/IHLP%20675l675w.jpg
11 | LTST-C170GKT | Lite-On Inc. | LED GREEN CLEAR SMD | 12,51,641 | In Stock | 3 | 14 | 42 | 5.77500 | ₹242.55 | LTST-C170GKT | https://mm.digikey.com/Volume0/opasdata/d220001/medias/docus/895/LTST-C170GKT.pdf | N/A | YLED0603R | https://mm.digikey.com/Volume0/opasdata/d220001/medias/images/1149/LTST-C170YKT%2CLTST-C170CKT%2CLTST-C170AKT%2CLTST-C170EKT%2CLTST-C170GKT.jpg
12 | 691137710002 | Würth Elektronik | TERM BLK 2POS SIDE ENTRY 5MM PCB | 40,471 | In Stock | 3 | 6 | 18 | 28.61300 | ₹515.03 | 691137710002 | https://www.we-online.com/components/products/datasheet/691137710002.pdf | N/A | WJ128V-5.0-2P | https://mm.digikey.com/Volume0/opasdata/d220001/medias/images/2284/MFG_691137710002_View2.jpg
13 | SI7617DN-T1-GE3 | Vishay Siliconix | MOSFET P-CH 30V 35A PPAK1212-8 | 1,07,401 | In Stock | 3 | 6 | 18 | 56.78800 | ₹1,022.18 | SI7617DN-T1-GE3 | https://www.vishay.com/docs/65164/si7617dn.pdf | N/A | FQP47P06 | https://mm.digikey.com/Volume0/opasdata/d220001/derivates/6/003/212/993/742%7E5882%7EDN%7E8_web%28640x640%29.jpg
14 | BSC030P03NS3GAUMA1 | Infineon Technologies | MOSFET P-CH 30V 25.4/100A 8TDSON | 3,736 | In Stock | 3 | 1 | 3 | 192.50000 | ₹577.50 | BSC030P03NS3G | https://www.infineon.com/dgdl/BSC030P03NS3+G_2.0.pdf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 | N/A | BSC030P03NS3G | https://mm.digikey.com/Volume0/opasdata/d220001/medias/images/6173/448%7EPPG-TDSON-8-1%7E%7E8.jpg
15 | CR0805-FX-1002ELF | Bourns Inc. | RES SMD 10K OHM 1% 1/8W 0805 | 1,59,209 | In Stock | 3 | 10 | 30 | 1.68000 | ₹50.40 | CR0805-FX-1002ELF | https://bourns.com/docs/product-datasheets/cr.pdf?sfvrsn=574d41f6_14 | N/A | SCR0805J10K | https://mm.digikey.com/Volume0/opasdata/d220001/medias/images/505/CR0805-%282012-Metric%29.jpg
16 | CR0402-FX-3301GLF | Bourns Inc. | RES SMD 3.3K OHM 1% 1/16W 0402 | 40,017 | In Stock | 3 | 1 | 3 | 8.75000 | ₹26.25 | CR0402-FX-3301GLF | https://bourns.com/docs/product-datasheets/cr.pdf?sfvrsn=574d41f6_14 | N/A | RMC04023.3K5%N | https://mm.digikey.com/Volume0/opasdata/d220001/medias/images/505/CR0402-%281005-Metric%29.jpg
17 | CR0805-FX-1201ELF | Bourns Inc. | RES SMD 1.2K OHM 1% 1/8W 0805 | 88,545 | In Stock | 3 | 10 | 30 | 2.31000 | ₹69.30 | CR0805-FX-1201ELF | https://bourns.com/docs/product-datasheets/cr.pdf?sfvrsn=574d41f6_14 | N/A | 0805W8F1201T5E | https://mm.digikey.com/Volume0/opasdata/d220001/medias/images/505/CR0805-%282012-Metric%29.jpg
18 | CR0805-JW-331ELF | Bourns Inc. | RES SMD 330 OHM 5% 1/8W 0805 | 2,23,670 | In Stock | 3 | 10 | 30 | 1.50520 | ₹45.16 | CR0805-JW-331ELF | https://bourns.com/docs/product-datasheets/cr.pdf?sfvrsn=574d41f6_14 | N/A | CR0805J80331G | https://mm.digikey.com/Volume0/opasdata/d220001/medias/images/505/CR0805-%282012-Metric%29.jpg
19 | OS102011MS2QN1 | C&K | SWITCH SLIDE SPDT 100MA 12V | 54,244 | In Stock | 3 | 1 | 3 | 62.13000 | ₹186.39 | OS102011MS2QN1 | https://www.ckswitches.com/media/1428/os.pdf | N/A | MST-12D18G4 SPDT Slide Switch | https://mm.digikey.com/Volume0/opasdata/d220001/medias/images/981/MFG_OS102011MS2QN1.jpg
20 |  |  |  |  |  | 3 | 1 |  |  |  | XT90 |  |  | XT90H-F.G.Y
21 | LM27313XMFX/NOPB | Texas Instruments | IC REG BOOST ADJ 800MA SOT23-5 | 10,266 | In Stock | 3 | 1 | 3 | 161.00000 | ₹483.00 | LM27313XMFX/NOPB | https://www.ti.com/general/docs/suppproductinfo.tsp?distId=10 | N/A | XL4015E1 | https://mm.digikey.com/Volume0/opasdata/d220001/medias/images/4180/296%7E4073253-4%7EDBV%7E5.JPG
22 | MBR1045G | onsemi | DIODE SCHOTTKY 45V 10A TO2202 | 487 | In Stock | 3 | 1 | 3 | 73.50000 | ₹220.50 | MBR1045G | https://www.onsemi.com/pdf/datasheet/mbr1035-d.pdf | N/A | MBR1045G | https://mm.digikey.com/Volume0/opasdata/d220001/derivates/6/003/213/925/488%7E221B-04%7E%7E2_web%28640x640%29.jpg
23 | APXG160ARA331MH70G | Chemi-Con | CAP ALUM POLY 330UF 20% 16V SMD | 2,965 | In Stock | 3 | 1 | 3 | 78.75000 | ₹236.25 | APXG160ARA331MH70G | https://www.chemi-con.co.jp/products/relatedfiles/capacitor/catalog/PXGRA-e.PDF | N/A | HV1V337M1010PZ | https://mm.digikey.com/Volume0/opasdata/d220001/medias/images/908/PXG-Series.jpg
24 | 32102C | Murata Power Solutions Inc. | FIXED IND 1MH 450MA 568 MOHM TH | 210 | In Stock | 3 | 1 | 3 | 153.13000 | ₹459.39 | 32102C | https://search.murata.co.jp/Ceramy/image/img/P02A/kmp_3200.pdf | N/A | SLT130125T103MTB | https://mm.digikey.com/Volume0/opasdata/d220001/medias/images/4847/MFG_490_3200.jpg
25 | B41858C7228M000 | EPCOS - TDK Electronics | CAP ALUM 2200UF 20% 35V RADIAL | 794 | In Stock | 3 | 1 | 3 | 229.25000 | ₹687.75 | B41858C7228M000 | https://www.tdk-electronics.tdk.com/inf/20/30/db/aec/B41858.pdf?ref_disty=digikey | N/A | B41858C7228M000 | https://mm.digikey.com/Volume0/opasdata/d220001/medias/images/2479/B41858%20SERIES%2016x27mm.JPG
26 |  |  |  |  |  | 3 | 6 |  |  |  | XT60-F |  |  | XT60-F
Total Price |  |  |  |  |  |  |  |  |  | 11532.27

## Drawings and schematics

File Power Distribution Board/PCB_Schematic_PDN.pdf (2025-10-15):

# POWER INPUT

# Protection, fuse filter

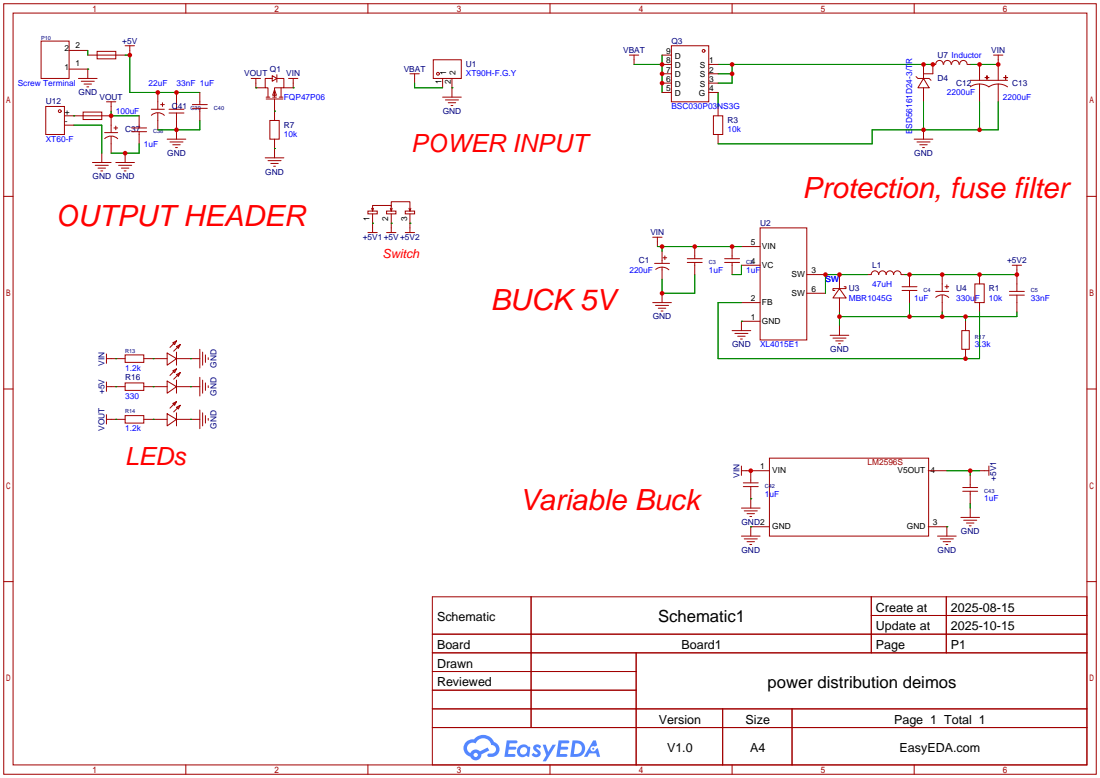
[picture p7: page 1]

Schematic | Schematic1 | Create at | 2025-08-15

Update at | 2025-10-15

Board | Board1 | Page | P1
Drawn | | power distribution deimos
Reviewed

Version | Size | Page 1 Total 1
V1.0 | A4 | EasyEDA.com

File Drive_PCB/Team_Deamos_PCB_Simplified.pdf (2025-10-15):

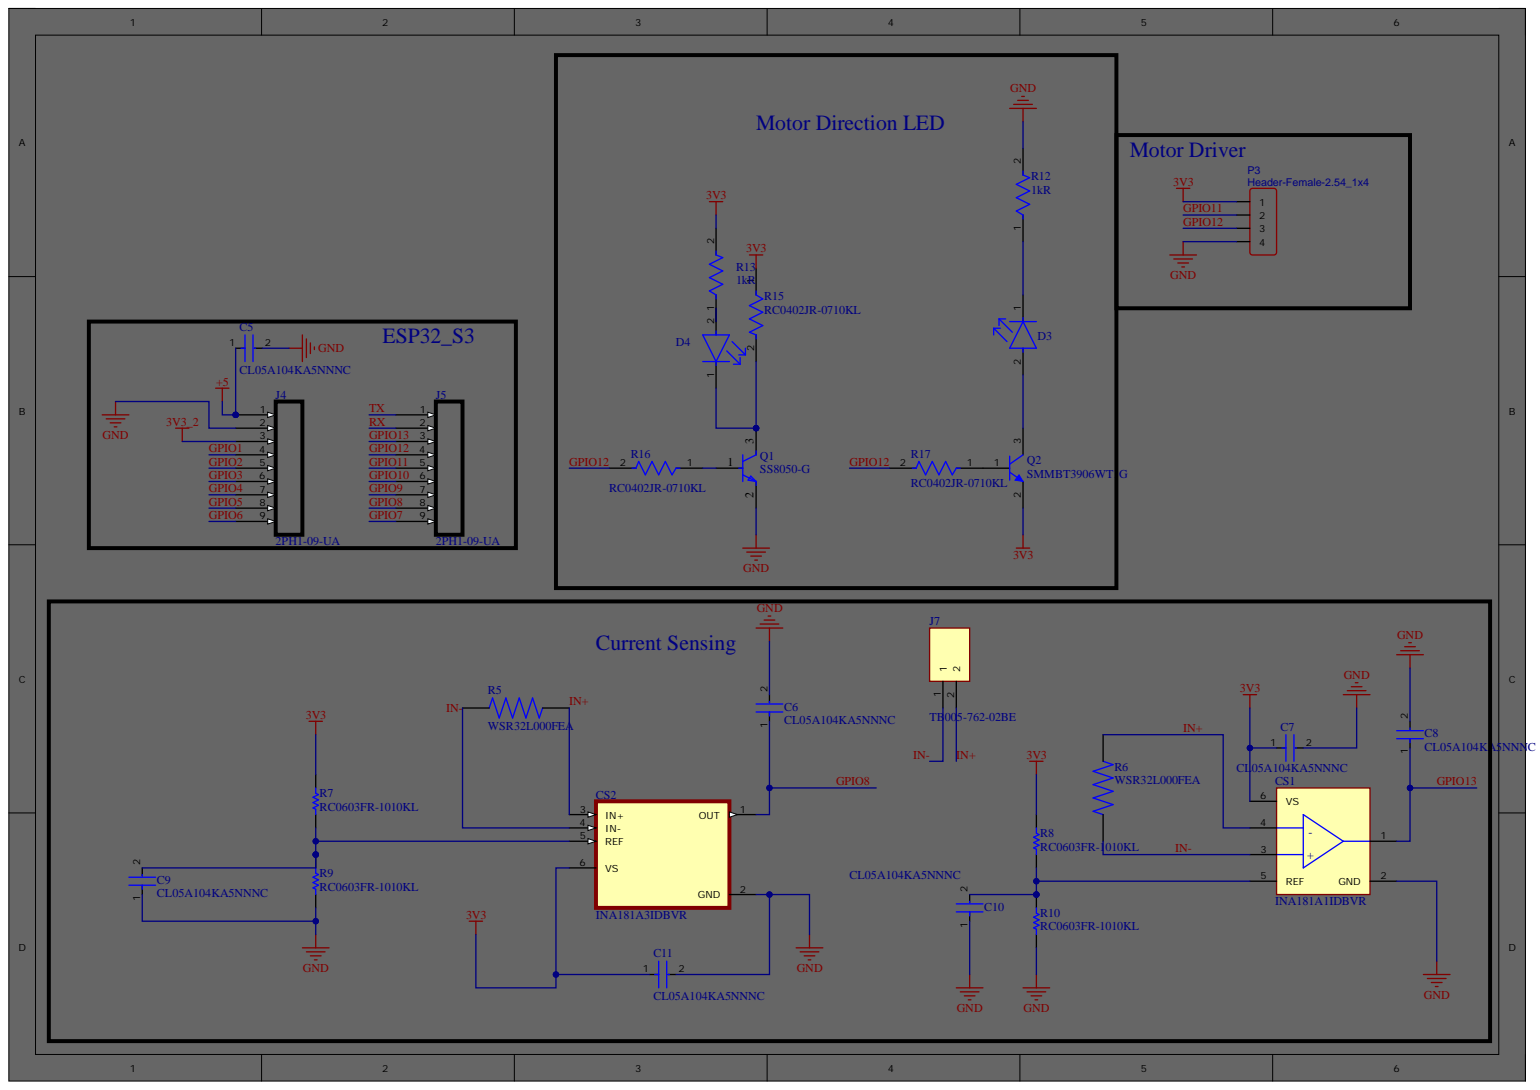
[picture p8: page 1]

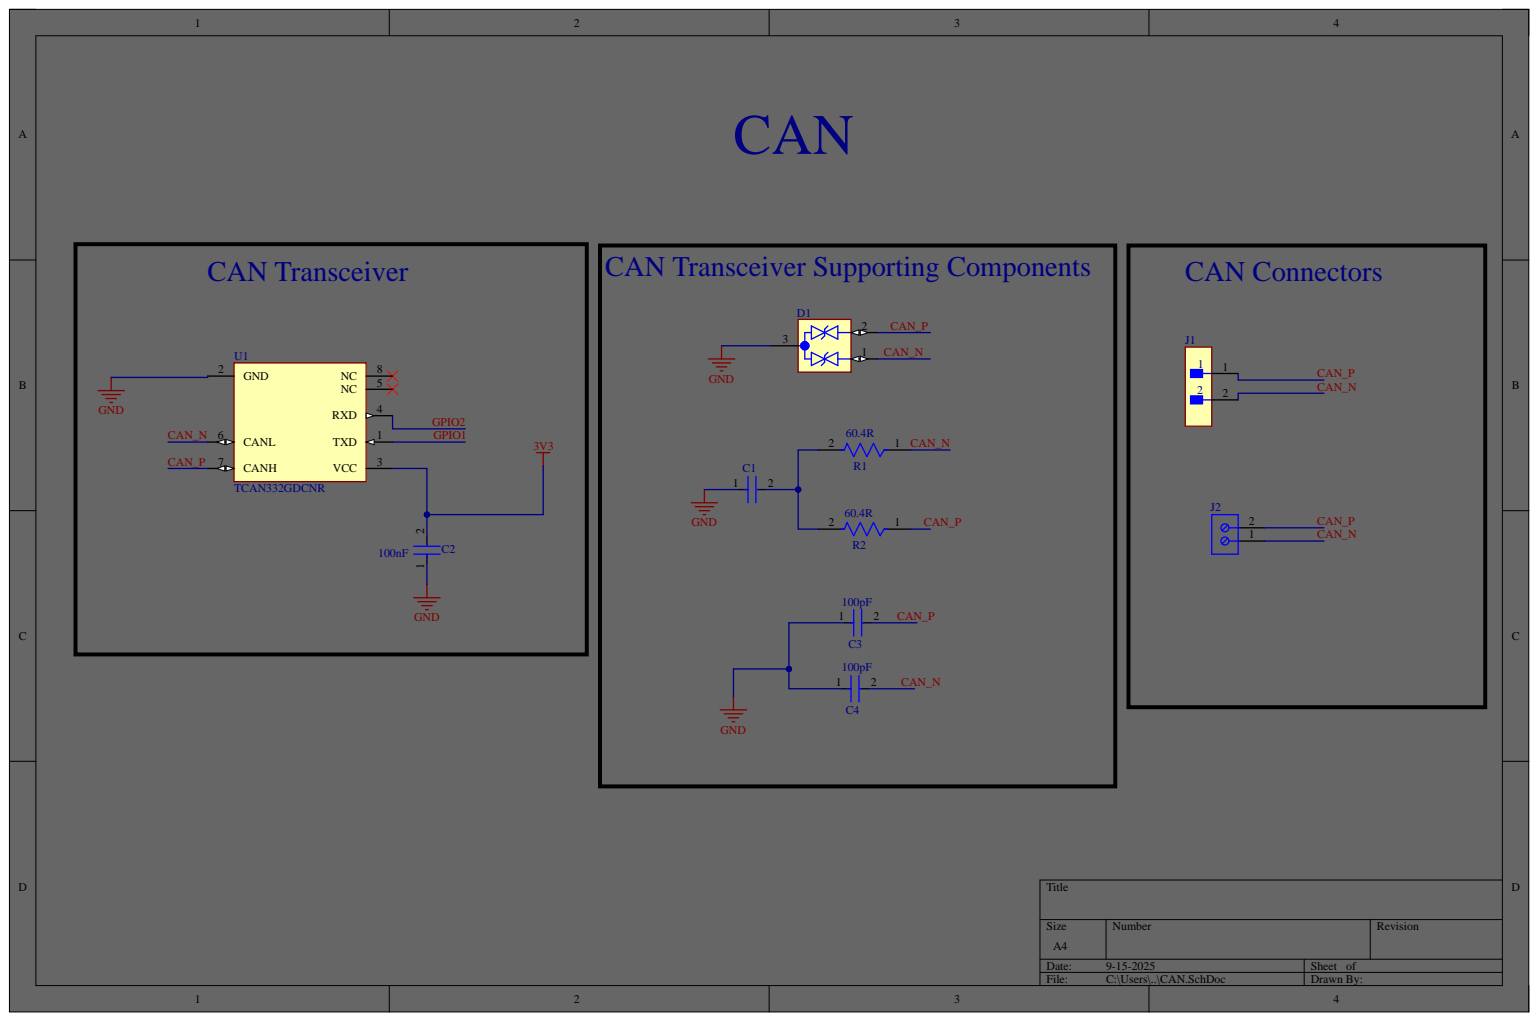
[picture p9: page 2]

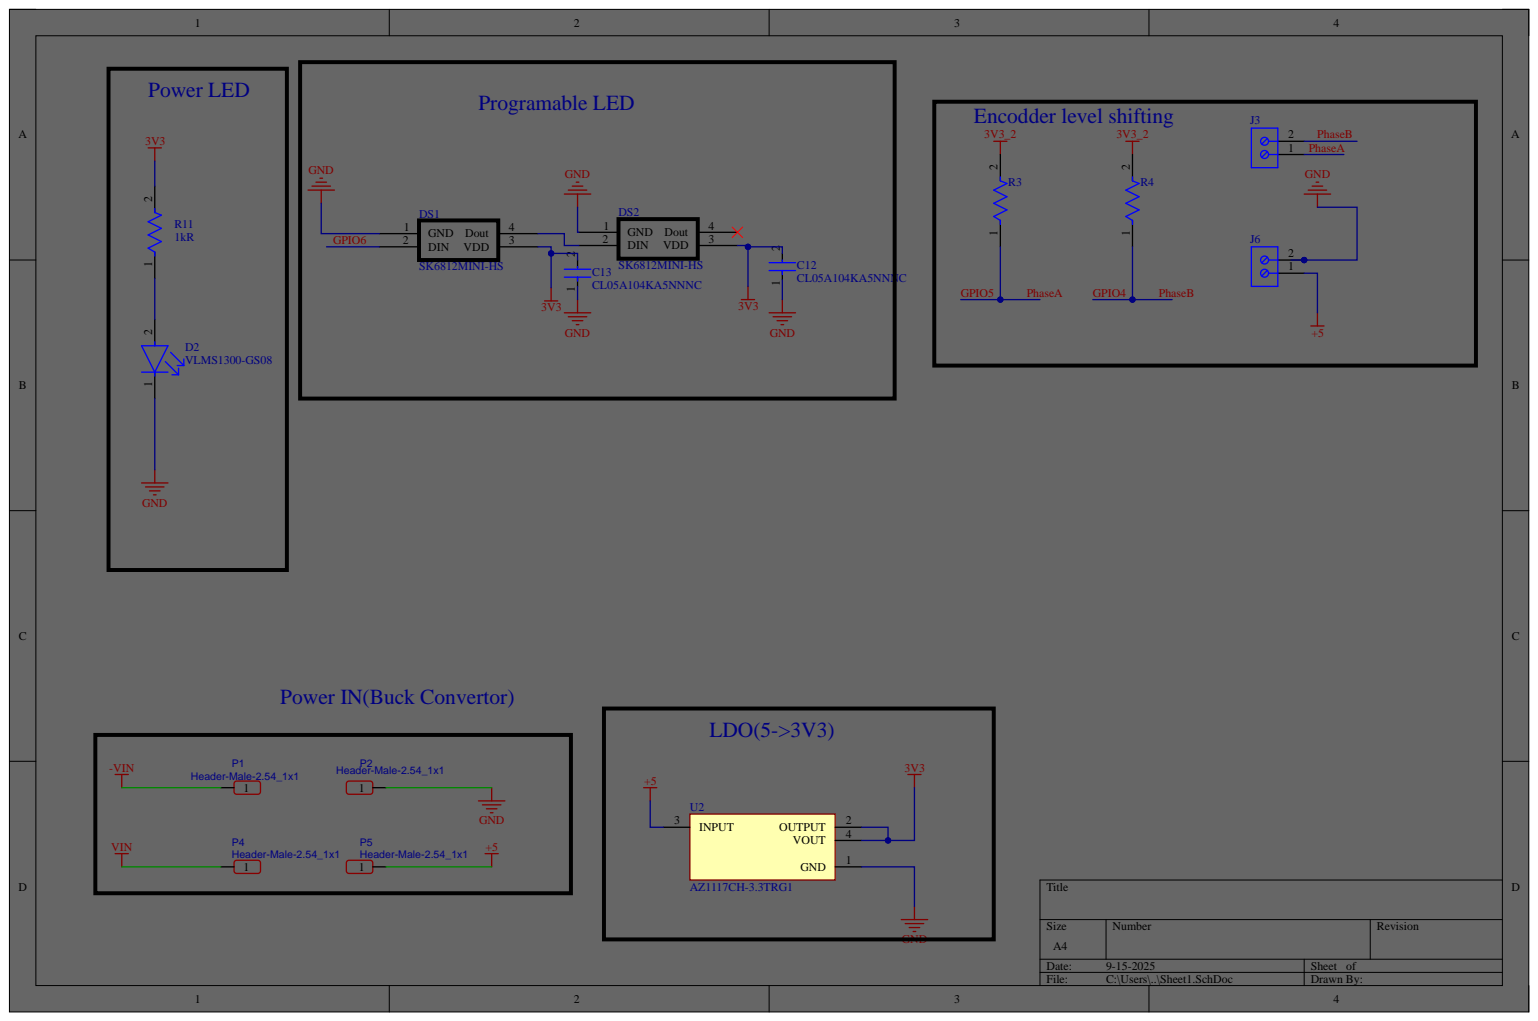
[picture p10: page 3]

Power IN(Buck Convertor)

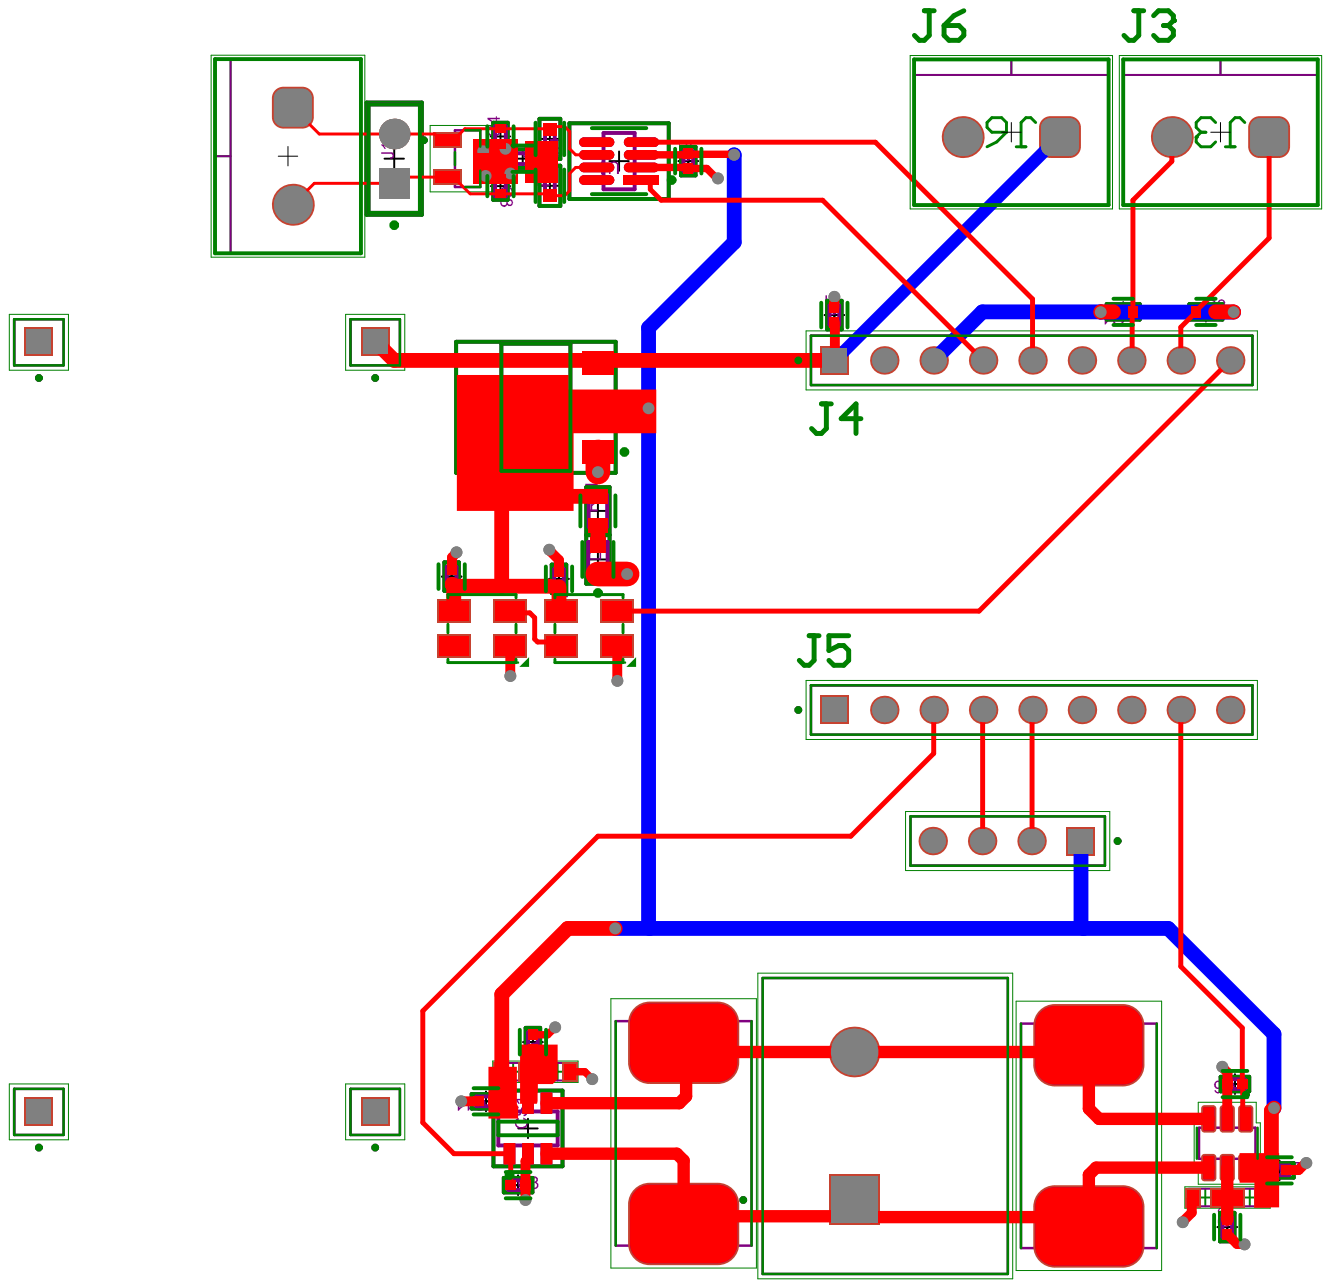
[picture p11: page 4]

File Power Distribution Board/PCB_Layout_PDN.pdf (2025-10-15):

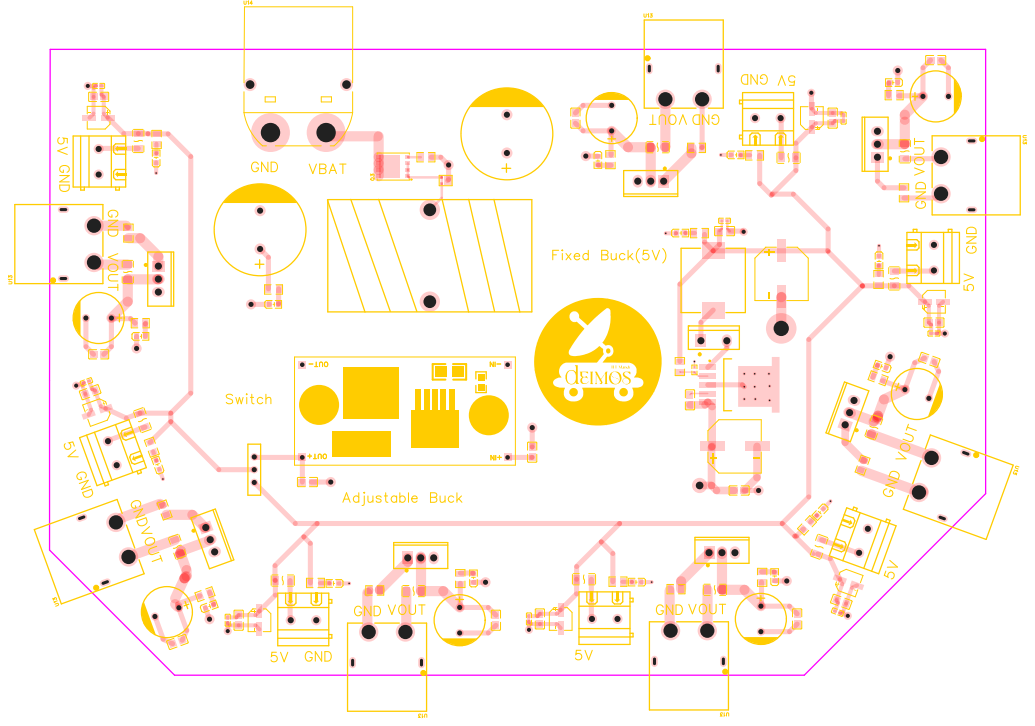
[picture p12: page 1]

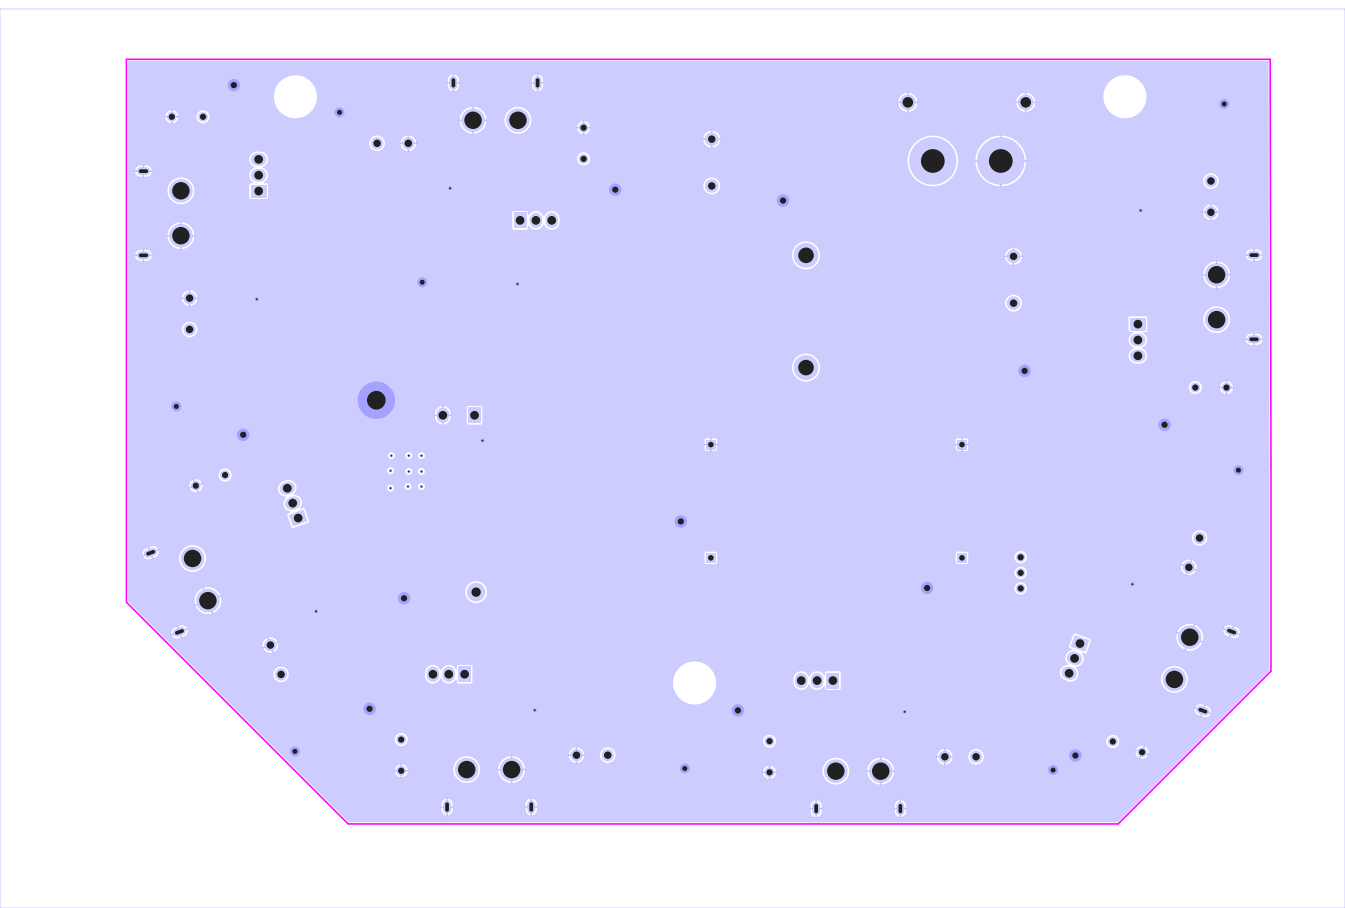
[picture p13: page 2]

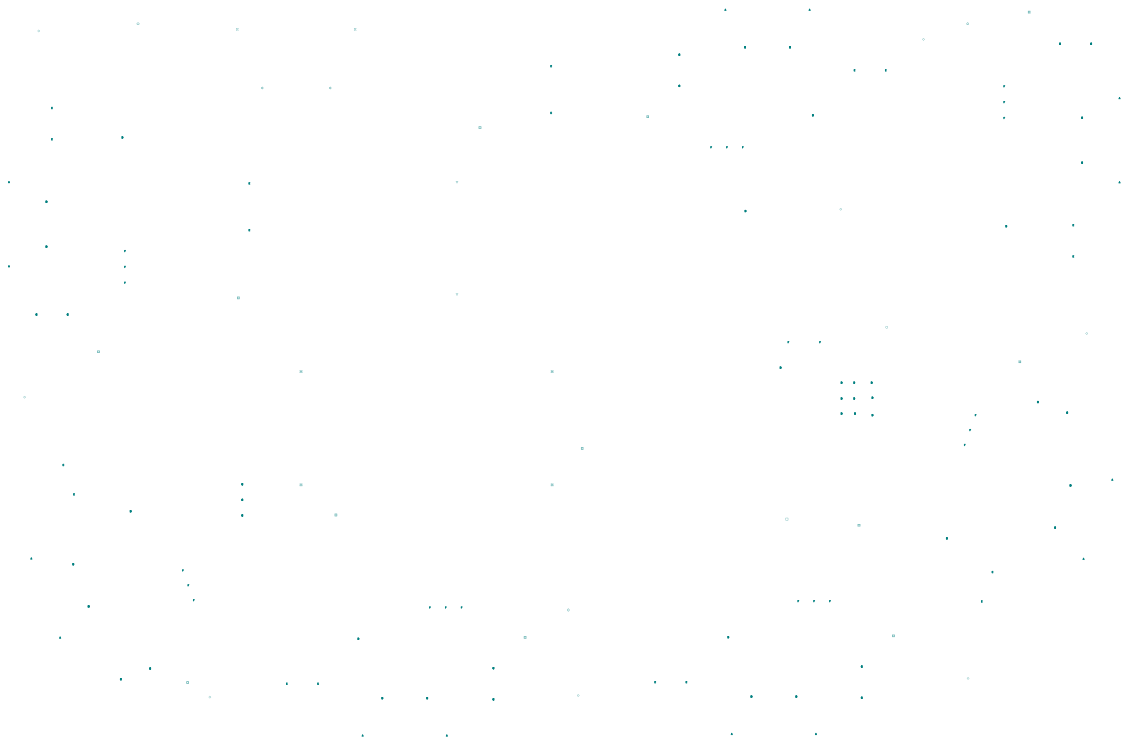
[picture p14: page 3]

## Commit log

2025-08-10 Managed project "Team_Deamos_PCB_Simplified" created from AD
    [Team_Deamos_PCB_Simplified.PrjPcb]
2025-10-15 Added Designs for PDN
    [BOM_PDN.xlsx.xlsx]
2025-10-15 Convert Drive_PCB from gitlink to real folder with files
    [CAN.SchDoc, PCB1.PcbDoc, PcbLib1.PcbLib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]
2025-10-22 Added Voltage and Power loss report
2025-11-07 Added files of arm and gripper PCBs (#22)
